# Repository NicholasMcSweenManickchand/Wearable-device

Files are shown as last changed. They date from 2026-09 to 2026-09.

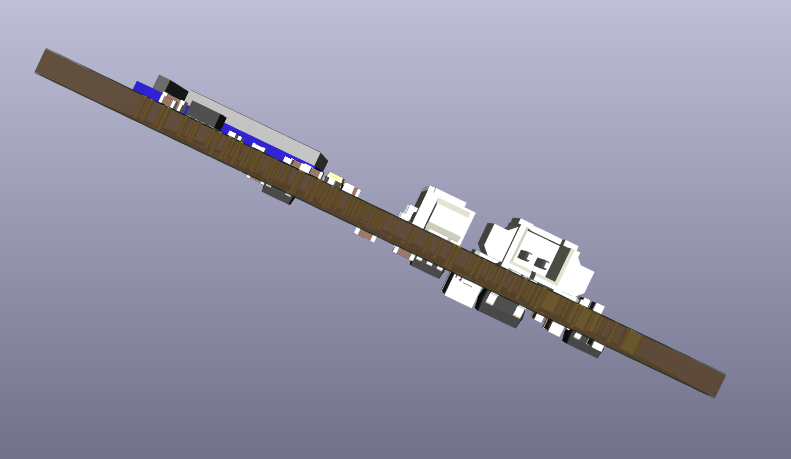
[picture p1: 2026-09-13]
Update 10_ Final 3D view side V1.png

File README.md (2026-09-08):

The goal of this project is to create a custom wearable that can gather data and interpret from that data the hear rate, step count, etc. 
I want it to do this locally on the micro controller (edge computing). This project will broadcast this data (via Bluetooth) into an app or
a UX of some kind to make the data easily readable for users.

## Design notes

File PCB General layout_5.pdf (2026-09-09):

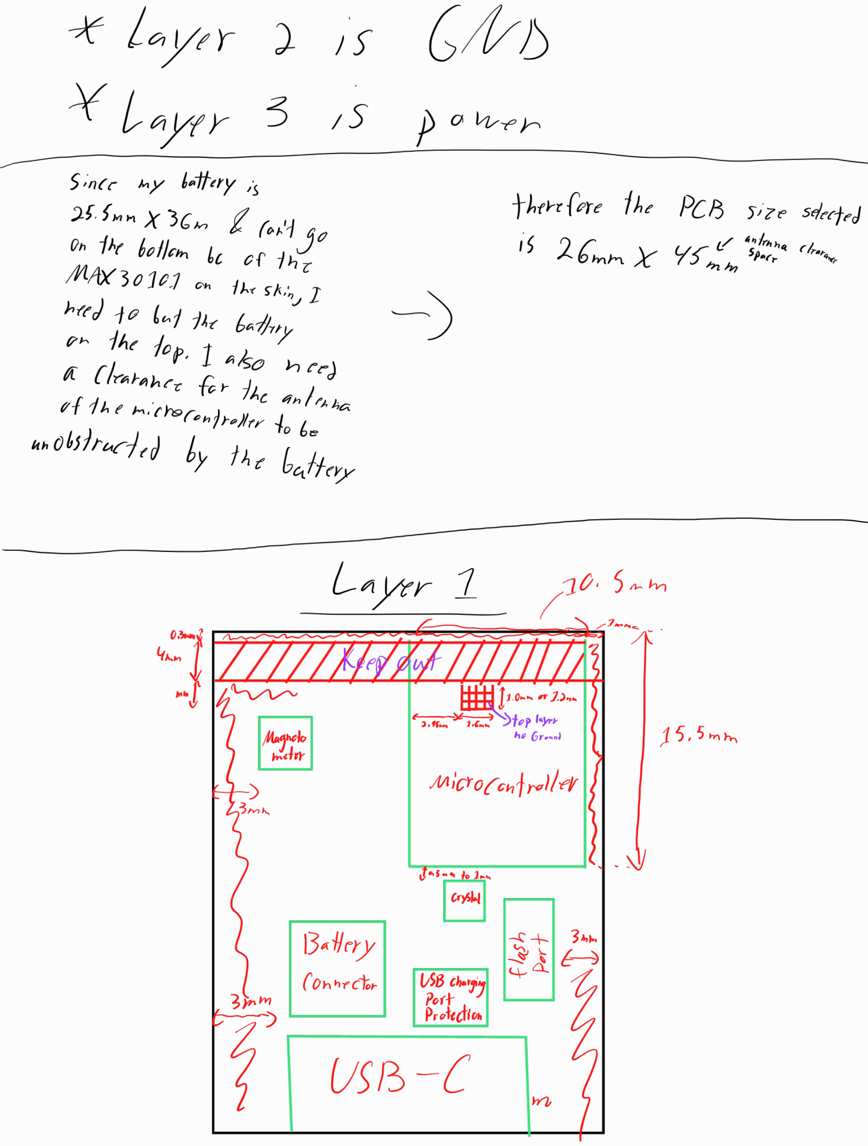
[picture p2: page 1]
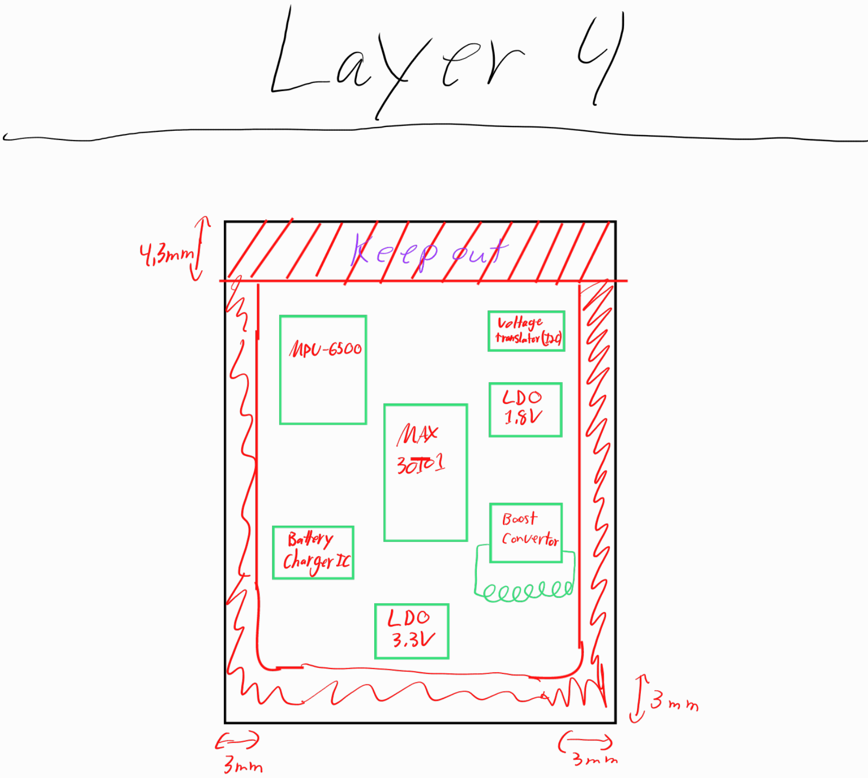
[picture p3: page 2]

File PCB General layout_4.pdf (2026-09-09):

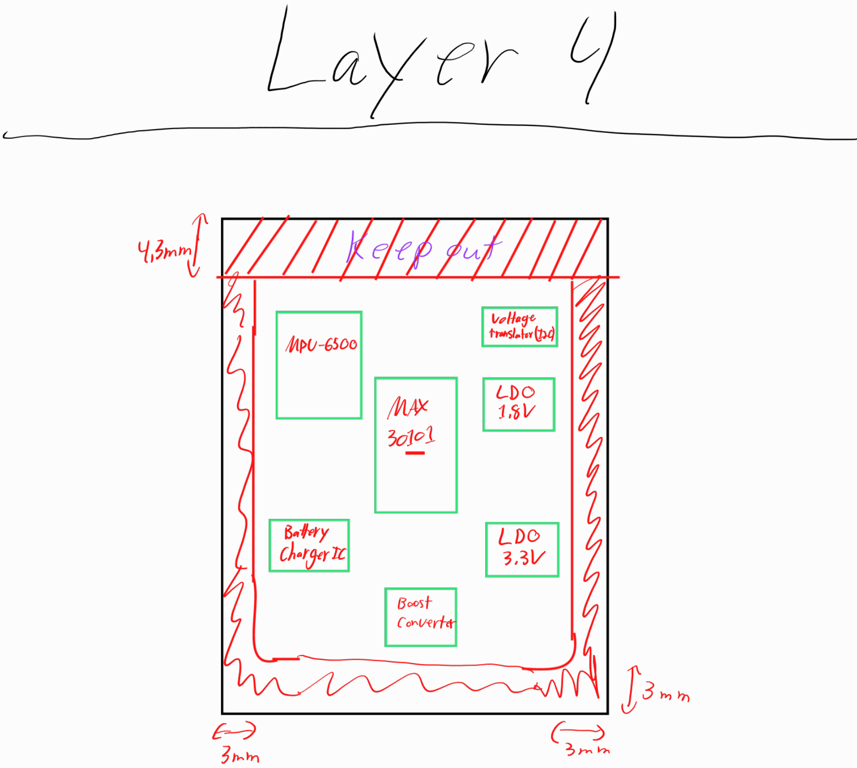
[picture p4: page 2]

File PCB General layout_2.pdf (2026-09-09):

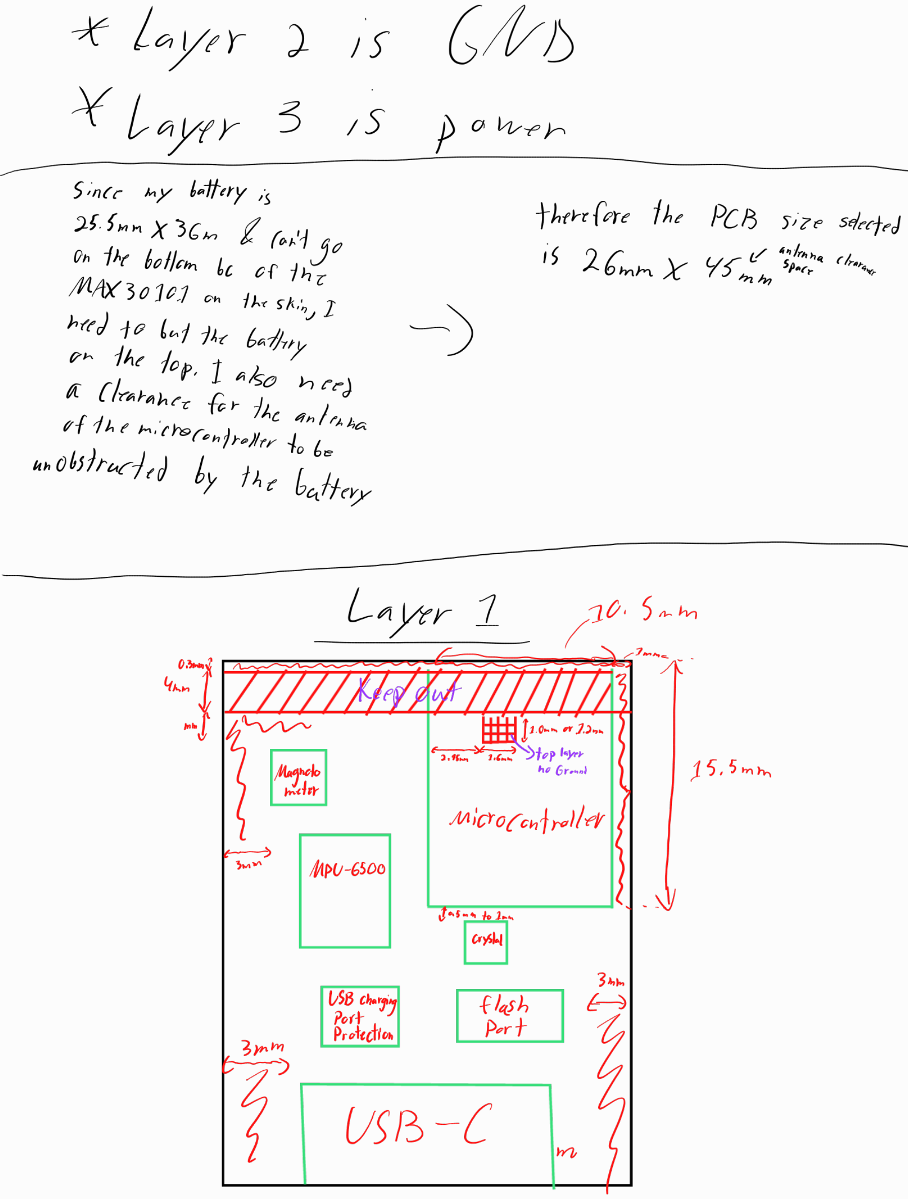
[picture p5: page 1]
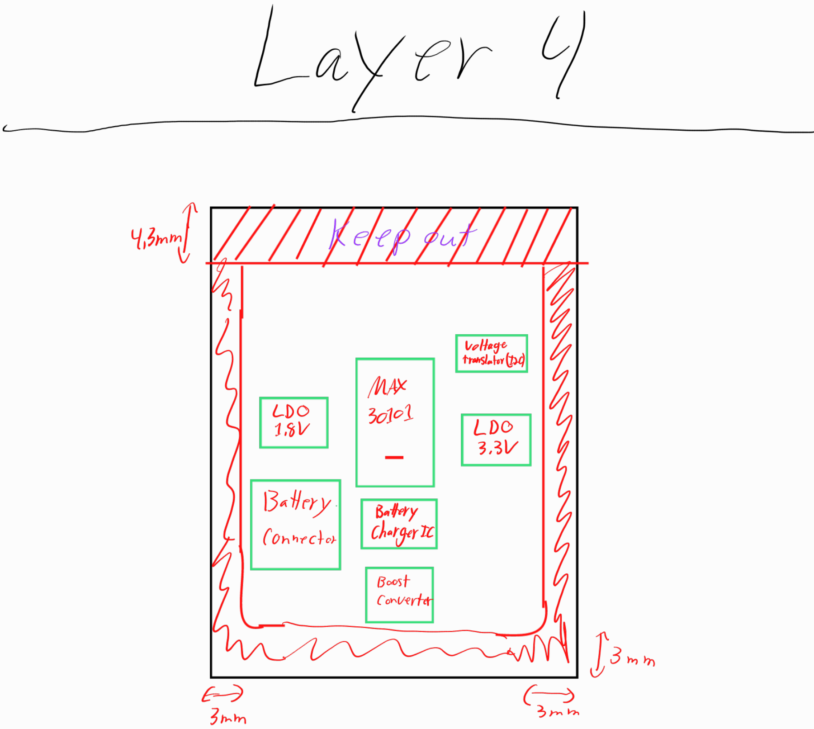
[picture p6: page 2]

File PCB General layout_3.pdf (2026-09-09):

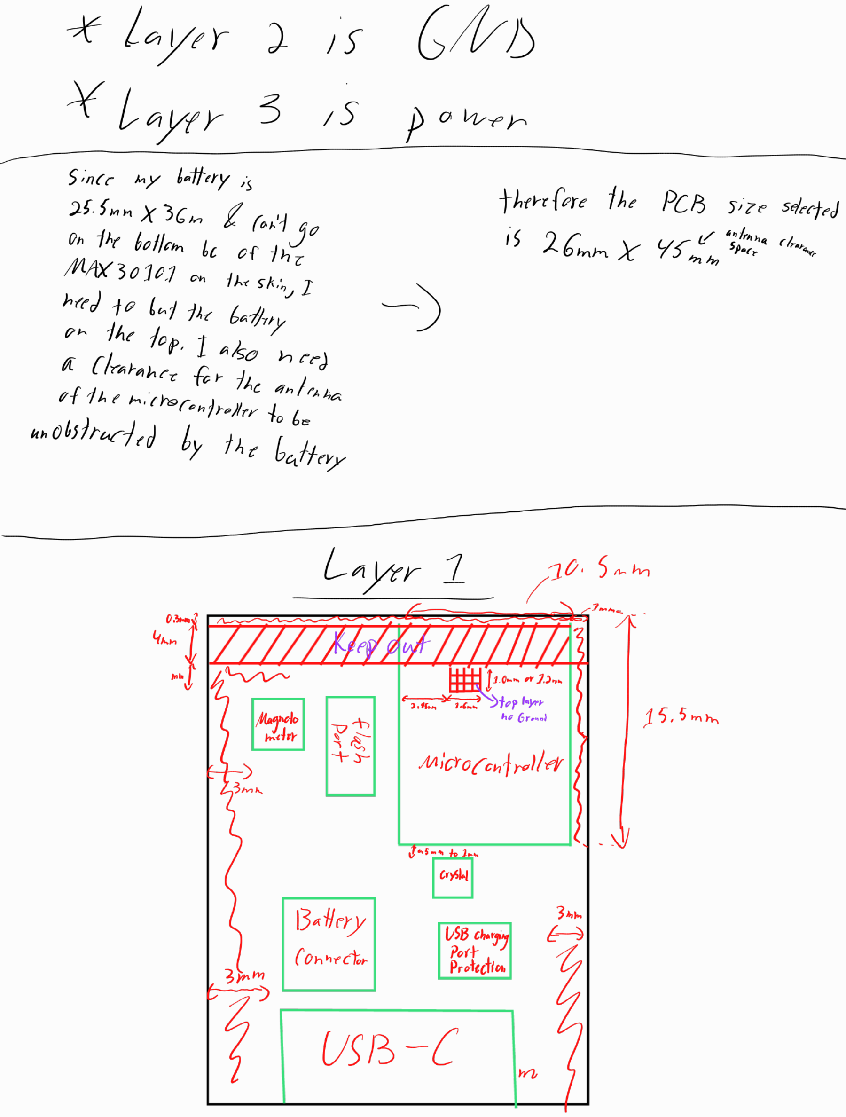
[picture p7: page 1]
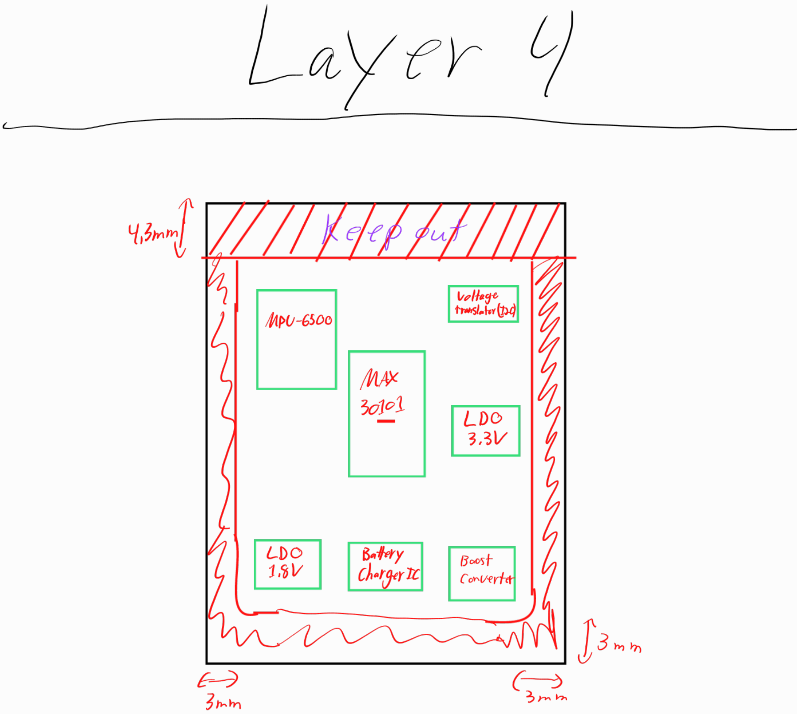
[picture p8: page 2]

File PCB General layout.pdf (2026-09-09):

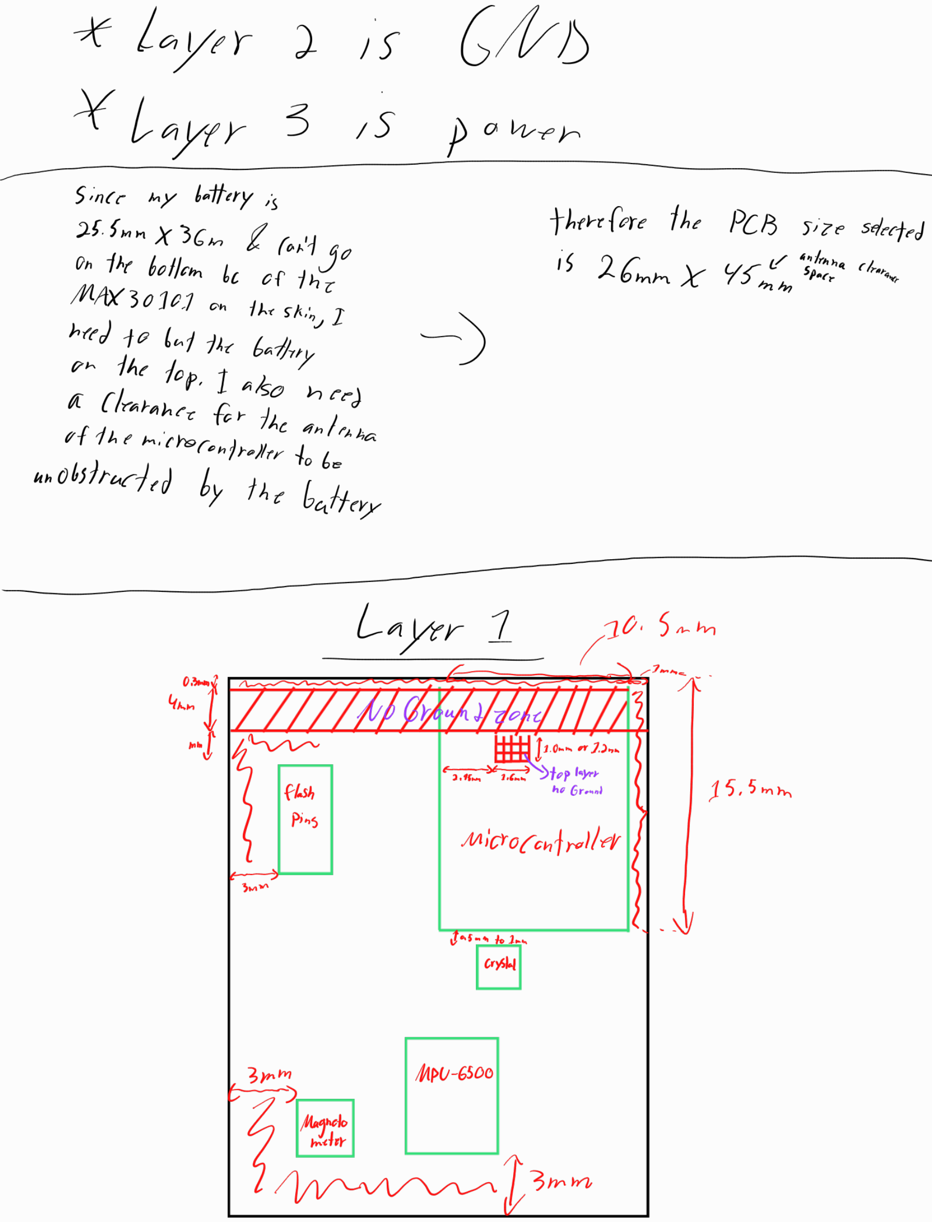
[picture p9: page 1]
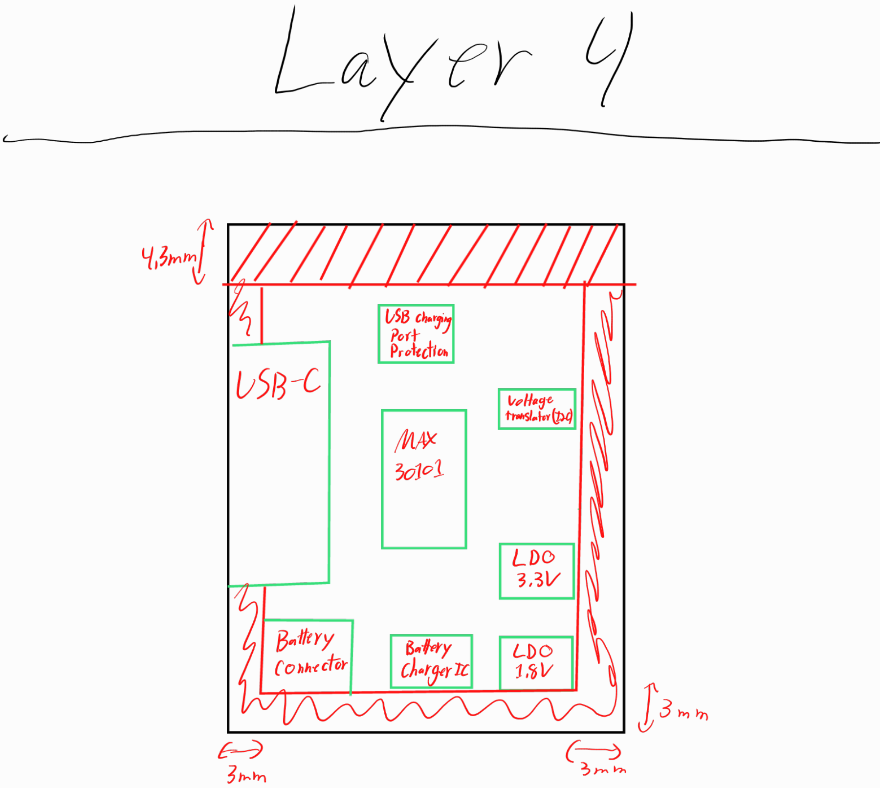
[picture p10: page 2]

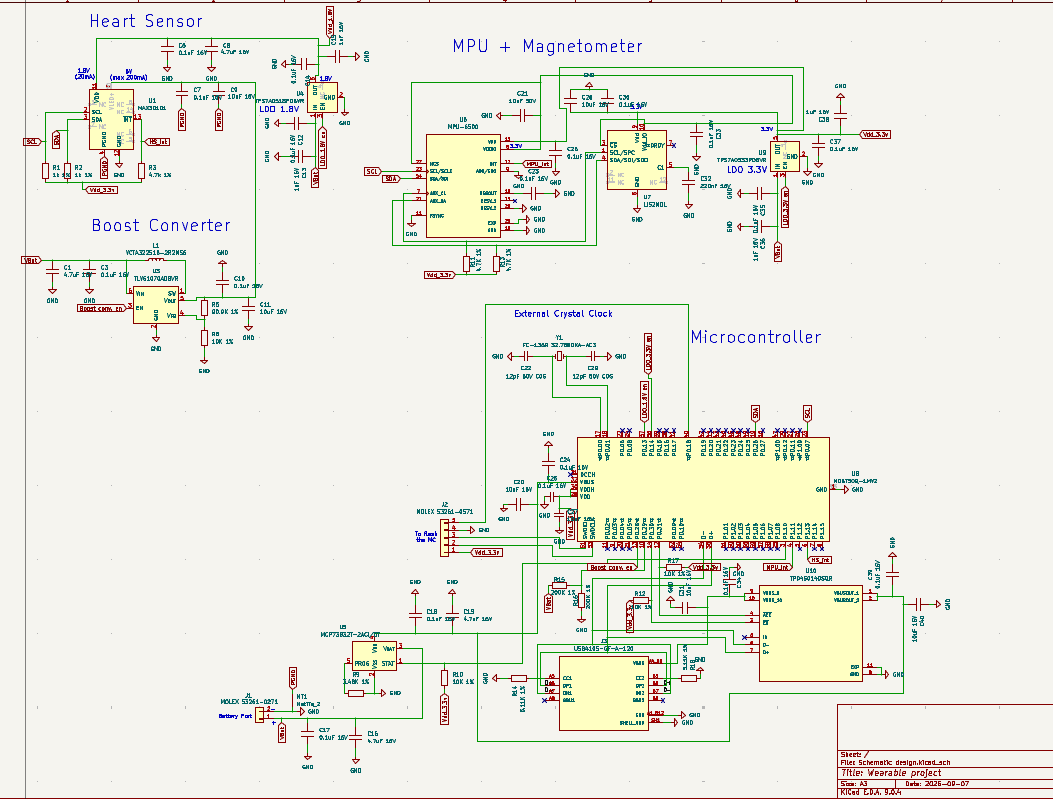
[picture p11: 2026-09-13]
Update 10_ Final schematic V1.png

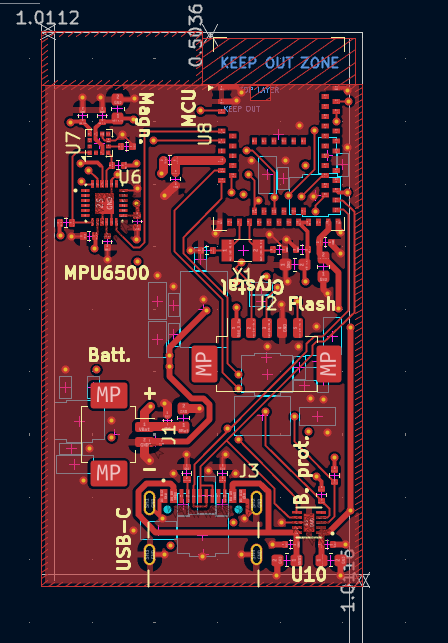
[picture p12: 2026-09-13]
Update 10_ Final L1 V1.png

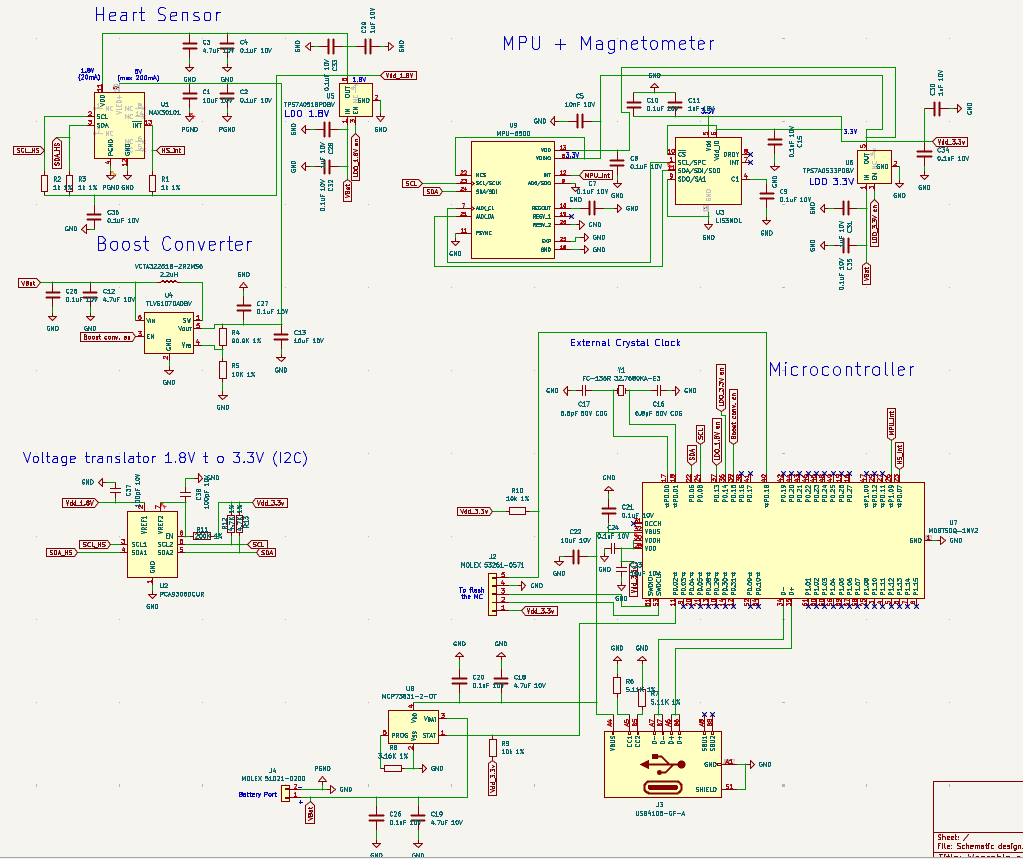
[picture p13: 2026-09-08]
Update 2_Full view of circuit.png

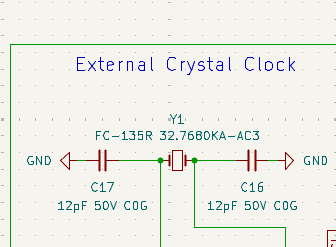
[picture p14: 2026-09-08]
Update 4_new crytal and clock system.png

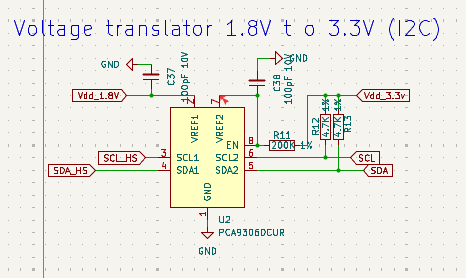
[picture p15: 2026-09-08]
Update 2_Voltage Translator.png

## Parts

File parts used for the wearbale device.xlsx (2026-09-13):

 | Heart beat sensor | Accel & gyro | Magnetometer | Boost converter | LDO (3.3V) | LDO (1.8V) | Microcontroller | Crystal clock | USB-C | Battery | Battery connector | Battery IC charger | Flash MC port | Battery connector (on board) | Voltage Level translater for I2C | USB Charging port protection
Part ID | MAX30101 | MPU-6500 | LIS2MDL | TLV61070ADBVR | TPS7A0533PDBV | TPS7A0518PDBVR | MDBT50Q-1MV2 | FC-135R 32.7680KA-AC3 | USB4105-GF-A | 402535 | MOLEX 51021-0200 | MCP73832-2-OT | MOLEX 53261-0571 | MOLEX 53261-0271 | PCA9306DCUR | TPD4S014DSQR
DataSheet | MAX30101 (https://www.analog.com/media/en/technical-documentation/data-sheets/MAX30101.pdf) | MPU-6500 (https://datasheet.octopart.com/MPU-6500-InvenSense-datasheet-138896167.pdf) | LIS2MDL | TLV61070A (https://www.ti.com/lit/ds/symlink/tlv61070a.pdf) | TPS7A05 (https://www.ti.com/lit/ds/symlink/tps7a05.pdf) | TPS7A05 (https://www.ti.com/lit/ds/symlink/tps7a05.pdf) | MDBT50Q-1MV2 (https://www.raytac.com/download/index.php?index_id=43) | Crystal (https://download.epsondevice.com/td/pdf/app/FC-135R_en.pdf) | USB-C connector (https://gct.co/files/specs/usb4105-spec.pdf) | Battery | Battery connector (https://www.molex.com/en-us/products/part-detail/510210200?display=pdf) | Battery charger (https://ww1.microchip.com/downloads/aemDocuments/documents/APID/ProductDocuments/DataSheets/MCP73831-Family-Data-Sheet-DS20001984H.pdf) | Flash MC Port (https://www.molex.com/content/dam/molex/molex-dot-com/products/automated/en-us/salesdrawingpdf/532/53261/532610571_sd.pdf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) | ON board bat con (https://www.molex.com/content/dam/molex/molex-dot-com/products/automated/en-us/salesdrawingpdf/532/53261/532610271_sd.pdf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) | Voltage translator (https://www.ti.com/lit/ds/symlink/pca9306.pdf?HQS=dis-dk-null-digikeymode-dsf-pf-null-wwe&ts=1788825051964) | USB protection IC (https://www.ti.com/lit/ds/symlink/tpd4s014.pdf?HQS=dis-dk-null-digikeymode-dsf-pf-null-wwe&ts=1788841786533)
Purchase link |  |  |  |  |  |  |  |  |  | Battery (https://www.amazon.ca/EEMB-402535-Rechargeable-Connector-Certified/dp/B08215N9R8)
Design checked on schematic? | YES | YES | YES | YES | YES | YES | YES | YES | YES | N/A | N/A | YES | YES | YES | YES | YES
PCB LAYER (1 or 4) (2 and 3 are power) | 4 | 1 | 1 | 4 | 4 | 4 | 1 | 1 | 1 | N/A | N/A | 4 | 1 | 1 | 4 | 1
Capacitor/ resistor setup (no traces) | YES | YES | YES | YES | YES | YES | YES | YES | YES | N/A | N/A | YES | YES | YES | YES | YES
Traces done (ignoring power & I2C & PGND) | YES | YES | YES | YES | YES | YES | YES | YES | YES | N/A | N/A | YES | YES | YES | DELETED | YES
Voltage needed (for power plane) | N/A | 3.3V | 3.3V | VBAT | VBAT | VBAT | 3.3V | N/A | N/A | N/A | N/A | N/A | 3.3V | VBAT | DELETED | N/A
Final check on PCB (kicad) | YES | YES | YES | YES | YES | YES | YES | YES | YES | N/A | N/A | YES | YES | YES | DELETED | YES

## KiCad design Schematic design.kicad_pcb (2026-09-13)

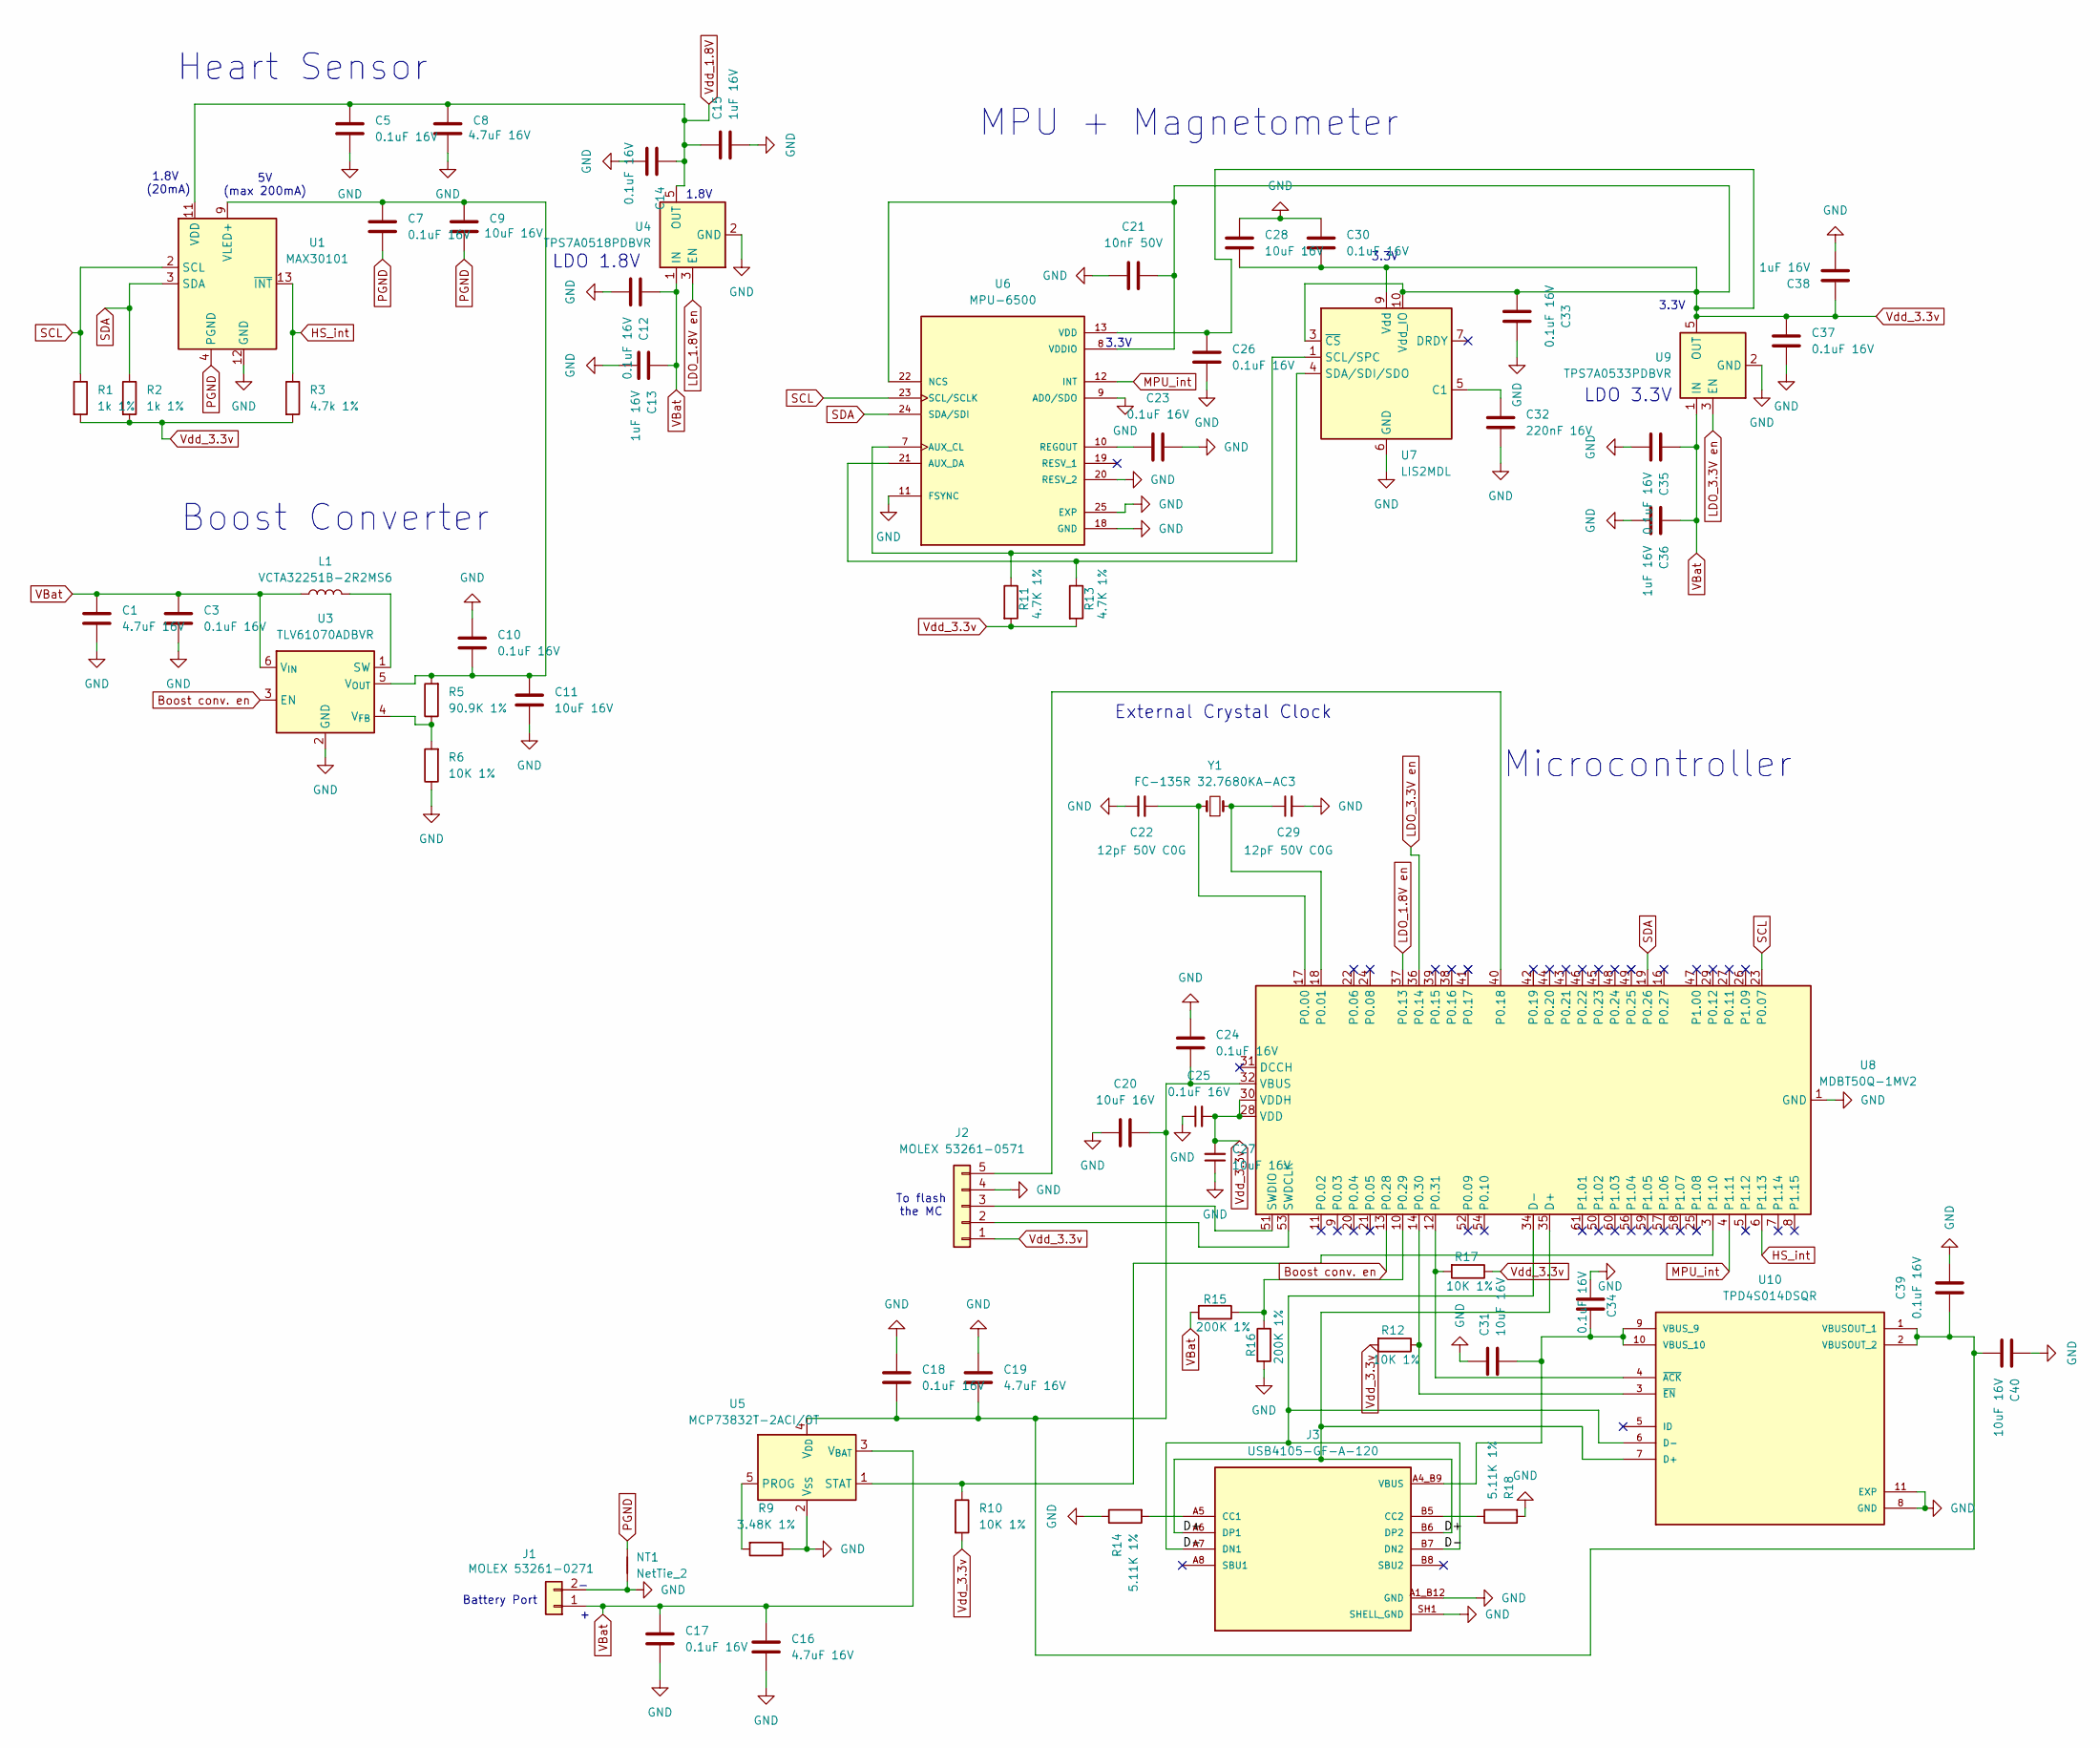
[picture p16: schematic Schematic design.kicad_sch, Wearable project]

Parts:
C1, C8, C16, C19: 4.7uF 16V; C_0603_1608Metric; MPN CL10A475KO8NQNC
C3, C5, C7, C10, C12, C14, C17, C18, C23, C24, C25, C26, C30, C33, C34, C35, C37, C39: 0.1uF 16V; C_0402_1005Metric; MPN CL05A104KO5NNNC
C9, C11, C20, C27, C28, C31, C40: 10uF 16V; C_0603_1608Metric; MPN CL10A106MO8NRNC
C13, C15, C36, C38: 1uF 16V; C_0603_1608Metric; MPN CL10A105KO8NNNC
C21: 10nF 50V; C_0402_1005Metric; MPN CL05B103KB5NNNC
C22, C29: 12pF 50V C0G; C_0402_1005Metric; MPN CL05C120JB5NNNC
C32: 220nF 16V; C_0402_1005Metric; MPN CL05B224KO5NNNC
J1: MOLEX 53261-0271; Molex_PicoBlade_53261-0271_1x02-1MP_P1.25mm_Horizontal; MPN 53261-0271
J2: MOLEX 53261-0571; Molex_PicoBlade_53261-0571_1x05-1MP_P1.25mm_Horizontal; MPN 53261-0571
J3: USB4105-GF-A-120; GCT_USB4105-GF-A-120; PARTREV B3
L1: VCTA32251B-2R2MS6; L_1210_3225Metric; MPN VCTA32251B-2R2MS6
NT1: NetTie_2
R1, R2: 1k 1%; R_0402_1005Metric; MPN RC0402FR-071KL
R3: 4.7k 1%; R_0402_1005Metric; MPN RC0402FR-074K7L
R5: 90.9K 1%; R_0402_1005Metric; MPN RC0402FR-0790K9L
R6, R10, R12, R17: 10K 1%; R_0402_1005Metric; MPN RC0402FR-0710KL
R9: 3.48K 1%; R_0402_1005Metric; MPN RC0402FR-073K48L
R11, R13: 4.7K 1%; R_0402_1005Metric; MPN RC0402FR-074K7L
R14, R18: 5.11K 1%; R_0402_1005Metric; MPN RC0402FR-075K11L
R15, R16: 200K 1%; R_0402_1005Metric; MPN RC0402FR-07200KL
U1: MAX30101; Maxim_OLGA-14_3.3x5.6mm_P0.8mm; MPN MAX30101EFD+T
U3: TLV61070ADBVR; SOT-23-6; MPN TLV61070ADBVR
U4: TPS7A0518PDBVR; SOT-23-5; MPN TPS7A0518PDBVR
U5: MCP73832T-2ACI/OT; SOT-23-5; MPN MCP73832T-2ACI/OT
U6: MPU-6500; QFN40P300X300X95-25N; PARTREV 1.3
U7: LIS2MDL; LGA-12_2x2mm_P0.5mm; MPN LIS2MDLTR
U8: MDBT50Q-1MV2; Raytac_MDBT50Q; MPN MDBT50Q-1MV2
U9: TPS7A0533PDBVR; SOT-23-5; MPN TPS7A0533PDBVR
U10: TPD4S014DSQR; SON40P200X200X80-11N; PARTREV E
Y1: FC-135R 32.7680KA-AC3; Crystal_SMD_3215-2Pin_3.2x1.5mm; MPN FC-135R 32.7680KA-AC3

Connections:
/D+: J3.A6 (DP1), J3.B6 (DP2), U8.35 (D+), U10.7 (D+)
/D-: J3.A7 (DN1), J3.B7 (DN2), U8.34 (D-), U10.6 (D-)
Boost conv. en: U3.3 (EN), U8.13 (P0.28)
GND: C1.2, C3.2, C5.2, C8.2, C10.1, C11.2, C12.2, C13.2, C14.2, C15.2, C16.2, C17.2, C18.1, C19.1, C20.1, C21.2, C22.1, C23.2, C24.1, C25.1, C26.1, C27.1, C28.2, C29.2, C30.2, C31.2, C32.1, C33.2, C34.1, C35.2, C36.2, C37.2, C38.2, C39.2, C40.2, J1.2, J2.4, J3.A1_B12 (GND), J3.B1_A12 (GND), J3.SH1 (SHELL_GND), J3.SH2 (SHELL_GND), J3.SH3 (SHELL_GND), J3.SH4 (SHELL_GND), NT1.1, R6.1, R9.1, R14.1, R16.2, R18.2, U1.12 (GND), U3.2 (GND), U4.2 (GND), U5.2 (V_{SS}), U6.9 (AD0/SDO), U6.11 (FSYNC), U6.18 (GND), U6.20 (RESV_2), U6.25 (EXP), U7.6 (GND), U7.8 (GND), U8.1 (GND), U8.2 (GND), U8.15 (GND), U8.33 (GND), U8.55 (GND), U9.2 (GND), U10.8 (GND), U10.11 (EXP)
HS_int: R3.1, U1.13 (~INT), U8.6 (P1.13)
LDO_1.8V en: U4.3 (EN), U8.37 (P0.13)
LDO_3.3V en: U8.36 (P0.14), U9.3 (EN)
MPU_int: U6.12 (INT), U8.4 (P1.11)
unnamed: J2.2, U8.53 (SWDCLK)
unnamed: J2.3, U8.51 (SWDIO)
unnamed: J2.5, U8.40 (P0.18)
unnamed: J3.A5 (CC1), R14.2
unnamed: J3.B5 (CC2), R18.1
unnamed: L1.2, U3.1 (SW)
unnamed: R5.1, R6.2, U3.4 (V_{FB})
unnamed: C7.1, C9.1, C10.2, C11.1, R5.2, U1.9 (VLED+), U1.10 (VLED+), U3.5 (V_{OUT})
unnamed: R9.2, U5.5 (PROG)
unnamed: R10.1, U5.1 (STAT), U8.3 (P1.10)
unnamed: R11.1, U6.7 (AUX_CL), U7.1 (SCL/SPC)
unnamed: R13.1, U6.21 (AUX_DA), U7.4 (SDA/SDI/SDO)
unnamed: C23.1, U6.10 (REGOUT)
unnamed: C32.2, U7.5 (C1)
unnamed: C22.2, U8.17 (P0.00), Y1.1
unnamed: C29.1, U8.18 (P0.01), Y1.2
unnamed: R15.1, R16.1, U8.10 (P0.29)
unnamed: C18.2, C19.2, C20.2, C24.2, C39.1, C40.1, U5.4 (V_{DD}), U8.32 (VBUS), U10.1 (VBUSOUT_1), U10.2 (VBUSOUT_2)
unnamed: R17.2, U8.12 (P0.31), U10.4 (~ACK)
unnamed: R12.1, U8.14 (P0.30), U10.3 (~EN)
PGND: C7.2, C9.2, NT1.2, U1.4 (PGND)
SCL: R1.1, U1.2 (SCL), U6.23 (SCL/SCLK), U8.23 (P0.07)
SDA: R2.1, U1.3 (SDA), U6.24 (SDA/SDI), U8.19 (P0.26)
VBUS: C31.1, C34.2, J3.A4_B9 (VBUS), J3.B4_A9 (VBUS), U10.9 (VBUS_9), U10.10 (VBUS_10)
VBat: C1.1, C3.1, C12.1, C13.1, C16.1, C17.1, C35.1, C36.1, J1.1, L1.1, R15.2, U3.6 (V_{IN}), U4.1 (IN), U5.3 (V_{BAT}), U9.1 (IN)
Vdd_1.8V: C5.1, C8.1, C14.1, C15.1, U1.11 (VDD), U4.5 (OUT)
Vdd_3.3v: C21.1, C25.2, C26.2, C27.2, C28.1, C30.1, C33.1, C37.1, C38.1, J2.1, R1.2, R2.2, R3.2, R10.2, R11.2, R12.2, R13.2, R17.1, U6.8 (VDDIO), U6.13 (VDD), U6.22 (NCS), U7.3 (~CS), U7.9 (Vdd), U7.10 (Vdd_IO), U8.28 (VDD), U8.30 (VDDH), U9.5 (OUT)

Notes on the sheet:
To flash the MC
1.8V (20mA)
Battery Port
LDO 3.3V
5V (max 200mA)
3.3V
LDO 1.8V
1.8V
Microcontroller
Heart Sensor
Boost Converter
External Crystal Clock
MPU + Magnetometer
3.3V

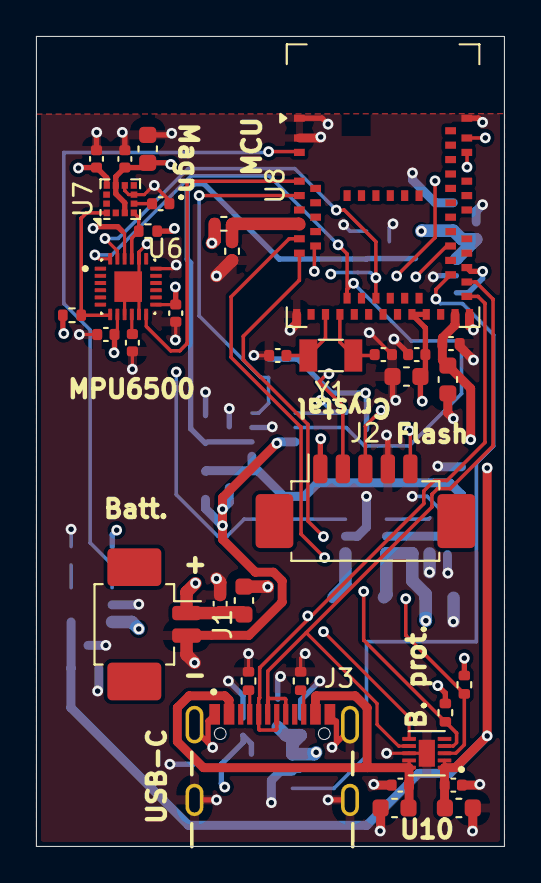
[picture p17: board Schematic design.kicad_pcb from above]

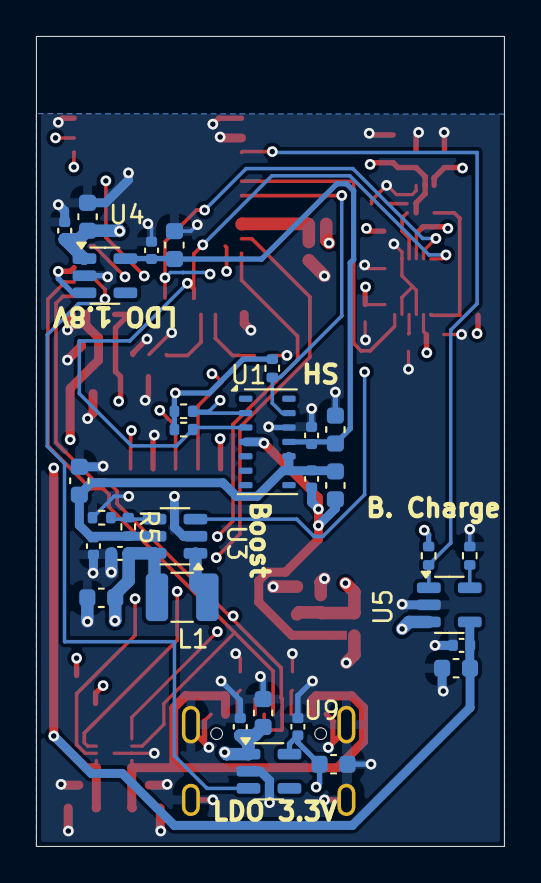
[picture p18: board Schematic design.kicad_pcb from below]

Board: 4 copper layers, 26.0 x 45.0 mm, 67 parts (31 on the bottom side), 35 nets.

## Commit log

2026-09-07 Added screeshots of schematic and shematic file
    The is the schematic layout for my first commit, almost complete but i will do some verifications to endure all is good before moving on to the PCB design
    [Schematic design.kicad_sch]
2026-09-08 Add project description to README
    Outline project goals for wearable device data collection and display.
2026-09-08 Add files via upload
    I noticed when making my bill of materials (BOM) that the MPU6050 and MAX30105 were discontinued/obsolete. Luckily, the MAX30105, MAX30102, and MAX30101 all have the same blueprint. However, only the MAX30101 and MAX30105 have the green light, which is optimal for sensing heartbeat. Even better, the MAX30101 and MAX30105 are electrically the same. The difference lies in the internal firmware, but the MAX30101 is actually better for a wearable anyways.
    For the MPU6050, I selected the similar MPU6500, but had to install a library and symbol from SnapEDA. I then just rewired it appropriately based on the datasheet.
    I then noticed a logical problem while reviewing the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
    [Schematic design.kicad_sch]
2026-09-08 Add files via upload
    I noticed I did not connect the pull-up resistors on the Voltage translator (3.3v side) properly. it is connected properly now. I also gave all the elements a footprint and a name for the BOM.
    [Schematic design.kicad_sch]
2026-09-08 Add files via upload
    Added a USB Charging port protection IC (TPD4S014DSQR) in order to protect against low quality chargers or incompatible voltage chargers.
    [Schematic design.kicad_sch]
2026-09-08 Add files via upload
    Final review before I start the PCB design. Systematically looked at every module 1 by 1 against its datasheet and caught some more mistakes I had made. I am truly confident in the circuit now and will start PCB routing.
    [Schematic design.kicad_sch]
2026-09-09 Add files via upload
    This is a general layout for PCB (drawn before actually attempting the architecture), This is currently version one. I have my heart sensor, power system, and I2C voltage translator at layer 4. On la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
2026-09-09 Add files via upload
    Unfortunately, I realized that the old magnetometer I was using was obsolete. I therefore used a similar part with similar routing and switched it out. LIS3MDL->LIS2MDL
2026-09-09 Add files via upload
    I forgot to commit for every general layout, but here are the 3 most recent layout i have tried. Still no optimal to my taste. The USB-C makes holes through the PCB, I want to account for that better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
2026-09-10 Add files via upload
    Started the PCB routing in KiCAD. I put my Update_5 drawing into the software and made some modifications to the layout given that the sizes in my hand drawn layout were not 100% accurate and thus in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
2026-09-11 Add files via upload
    Traces done (excluding power) for External crystal, USB-C, Battery port. protect. and magnetometer on layer 1, also I have changed what pins I am using on the Micro-controller now that I can see the 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
2026-09-11 Add files via upload
    Interestingly, I noticed in the MAX30101's datasheet that the SDA, SCl and INT pins could handle up to 5V from GND. So the whole voltage translator for the I2C communication was unnecessary. I also c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
2026-09-13 First Final PCB and Schematic of the wearable
    Changed some circuitry around a little bit to complete the PCB traces and triple checked the PCB against the schematic while considering PCB design norms and rules. Overall the wearable device PCB se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
    [Schematic design.kicad_pcb, Schematic design.kicad_sch]
2026-09-13 Excel file used to keep track of updates
    I used this excel file to keep my updates, changes, component MPN and datasheets easily accessible for me.
    [parts used for the wearbale device.xlsx]
